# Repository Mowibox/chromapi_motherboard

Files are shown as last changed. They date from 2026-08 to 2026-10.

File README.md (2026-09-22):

# chromapi_motherboard

This repo contains a dedicated control HAT designed to manage the high-speed motion, power distribution, and sensor integration required for the quadruped robot [Chromapi](https://github.com/Mowibox/chromapi).








<p align="center">
  chromapi_motherboard
</p>

*Designed with KiCAD 10.*

## Table of contents

| Section | Description |
| --- | --- |
| [Project overview](#project-overview) | General description of the quadruped control board |
| [Authors](#authors) | Main contributors information |
| [Sponsors & Acknowledgements](#sponsors--acknowledgements) | Information about project sponsors and hardware support |
| [Resources & Documentation](#resources--documentation) | Links to datasheets, BOM, and design architectures |
| [Contributions](#contributions) | How to contribute to the repository |
| [License](#license) | Licensing information |

## Project overview

| Resource | Description | Location | Status |
| :--- | :--- | :--- | :--- |
| **💻 Firmware** | STM32 low-level drivers and communication protocol. | [`/firmware`](./firmware) | **Available** |
| **📐 Schematics** | PDF for hardware architecture | [`/hardware/schematic_pdf`](./hardware/schematic_pdf/chromapi_motherboard_v1.pdf) | **Available** |
| **📦 Manufacturing** | Gerbers, Drill files, BOM, and CPL for assembly. | [`/hardware/production`](./hardware/production/) | **Available** |

### Chromapi's Anatomy

* **🧠 The Brain**: The STM32G431KBT6 MCU handles real-time tasks: servo control, IMU fusion, and power monitoring. The Raspberry Pi runs high-level control, vision, and the Python SDK. They communicate through a custom UART bridge at 1 Mbps.

* **💪 The Muscles**: The SN74LVC1G126 and SN74LVC1G125 buffer the half-duplex RS485 bus for 12 Feetech STS3215 servos. The STM32 polls servo positions at 200 Hz.

* **❤️ The Heart**: The TPS51388 converts the 18650 2S battery voltage to 5V. The LD39050 generates the 3.3V rail. The INA226 monitors voltage, current, and power via I2C.

* **🛡️ The Immune System**: The CN3302 charges the two 18650 Li-ion cells through USB-C. The HY2120 provides protection against over-discharge, over-current, and short circuits.

* **👁️ The Senses & Balance**: The BMI088 IMU gives acceleration and angular velocity data with SPI. A Mahony filter runs at 100 Hz and outputs orientation as a quaternion. Four foot switches detect ground contact for gait timing.

* **🗣️ The Voice & Expression**: The MAX98357A drives the speaker via I2S communication. The ICS-43434 microphone captures audio through I2S. And the SN74AHCT1G125 level-shifts the 3.3V signal to 5V for the WS2812B RGB LEDs.

## Authors

| |
| :---: |
|  |
| [**Ousmane THIONGANE**](https://mowibox.github.io) |

## Sponsors & Acknowledgements

The hardware development of this board relies on the resources provided by the sponsors below.

### PCBWay

**[PCBWay](https://www.pcbway.com)** is a global manufacturer specializing in rapid prototyping and low-volume hardware production, offering advanced PCB fabrication, turnkey assembly, CNC machining, and 3D printing.

<p align="center">
  <a href="https://www.pcbway.com">
    PCBWay
  </a>
</p>

For this project, I utilized their sponsored [PCB manufacturing](https://www.pcbway.com/orderonline.aspx) and [assembly](https://www.pcbway.fr/pcb-assembly.html) (PCBA) services. Beyond fast production, their engineering team excels at detailed file reviews by cross-checking design options, BOMs, and footprints to prevent errors early. Their reliable component sourcing and rigorous verification were of great help in building a high-quality prototype for the Chromapi's motherbard.

---

> Huge thanks to all the hardware folks who reviewed my schematics, or gave me layout tips. I really appreciate your time and support!

## Resources & Documentation

| **⚡ Electrical Specs** | **📄 Bill of Materials** | **📡 Protocol Reference** | **🧠 Software Architecture** |
| :---: | :---: | :---: | :---: |
| Operating voltages, current limits, and thermal ratings. | Detailed BOM with part numbers and unit costs. | Custom UART protocol between RPi and STM32. | Firmware logic, DMA streams, and interrupt priorities. |
| 👉 [**View Specs**]() | 👉 [**View BOM**]() | 👉 [**View Protocol**]() | 👉 [**View Architecture**]() |

### Power Architecture

```mermaid
%%{init: {'themeVariables': {'edgeLabelBackground':'transparent'}}}%%
flowchart TD
    CHG[["USB-C charge<br/>CN3302"]] -.->|"charge → B+ ≈ 7.2–8.4V"| CELLS[("Battery<br/>18650 x2")]
    CELLS -->|"B+/BM/B-"| HY["HY2120<br/>BMS protection"]
    HY -->|"B+"| SW[["Power switch"]]

    SW -->|"V_BATT ≈ 7.2–8.4V"| SHUNT[["INA226 shunt sense<br/>2mΩ"]]
    SHUNT -->|"V_SYS ≈ 7.2–8.4V"| REG5{{"Voltage regulation<br/>TPS51388 · Fsw=600kHz"}}
    SHUNT -->|"V_SYS"| SERVOS(["Servomotors x12<br/>Feetech STS3215-C001"])

    REG5 -->|"+5V"| RPI["Raspberry Pi"]
    REG5 -->|"+5V"| FANPWR(["Fan<br/>Noctua NF-A4x10"])
    REG5 -->|"+5V"| LEDPWR(["RGB LEDs<br/>WS2812B"])
    REG5 -->|"+5V"| REG33{{"Voltage regulation<br/>LD39050 LDO"}}

    REG33 -->|"+3.3V"| MCU["MCU<br/>STM32G431KBT6"]
    REG33 -->|"+3.3V"| IMU["IMU<br/>BMI088"]
    REG33 -->|"+3.3V"| INA["Power monitor<br/>INA226"]
    REG33 -->|"+3.3V"| AUDIO["Speaker + Microphone<br/>MAX98357A / ICS-43434"]

    classDef power fill:#dd2757,color:#ffffff,stroke:none
    classDef voltreg fill:#ea684c,color:#ffffff,stroke:none
    classDef ic fill:#25b3ae,color:#ffffff,stroke:none
    classDef actuator fill:#c027e7,color:#ffffff,stroke:none
    classDef sensor fill:#5c5aed,color:#ffffff,stroke:none

    class CHG,CELLS,HY,SW power
    class REG5,REG33 voltreg
    class MCU,RPI,AUDIO ic
    class SERVOS,FANPWR,LEDPWR actuator
    class SHUNT,IMU,INA sensor
```

### Communication Architecture

```mermaid
%%{init: {'themeVariables': {'edgeLabelBackground':'transparent'}}}%%
flowchart LR
    RPI["Raspberry Pi"]
    MCU["STM32G431KBT6<br/>SYSCLK · 160 MHz"]
    SERVOS(["Servomotors x12<br/>STS3215-C001"])
    IMU["IMU<br/>BMI088"]
    PWR["Power Monitor<br/>INA226"]
    LED(["RGB LEDs<br/>WS2812B"])
    CAM["Wide Angle Camera<br/>IMX219-D160"]
    AUDIO["Speaker + Microphone<br/>MAX98357A / ICS-43434"]
    FAN(["Fan<br/>Noctua NF-A4x10"])

    RPI <-->|"Custom bridge protocol<br/>UART1 · 1 Mbps · 100 Hz control loop"| MCU
    MCU <-->|"RS485 half-duplex<br/>USART2 · 1 Mbps · 200 Hz poll"| SERVOS
    MCU <-->|"SPI1 · 5 MHz · 400 Hz ODR"| IMU
    MCU <-->|"I2C1 · 400 kHz · 10 Hz poll"| PWR
    MCU -->|"PWM+DMA · 800 kHz"| LED

    RPI -->|"CSI-2"| CAM
    RPI <-->|"I2S"| AUDIO
    RPI <-->|"PWM + Tacho"| FAN

    classDef ic fill:#25b3ae,color:#ffffff,stroke:none
    classDef actuator fill:#c027e7,color:#ffffff,stroke:none
    classDef sensor fill:#5c5aed,color:#ffffff,stroke:none

    class RPI,MCU,AUDIO ic
    class SERVOS,LED,FAN actuator
    class IMU,PWR,CAM sensor
```

## Contributions

Contributions are always welcome!

* **Report Issues:** Found an error or have a feature request? Create a new issue [here.](https://github.com/Mowibox/chromapi_motherboard/issues/new/choose)
* **Fix Bugs & Add Features:** Find out where you can lend a hand by checking out [existing issues.](https://github.com/Mowibox/chromapi_motherboard/issues)

## License

This project is licensed under the Apache 2.0 License. See the [LICENSE](https://github.com/Mowibox/chromapi_motherboard/blob/main/LICENSE) file for more details.

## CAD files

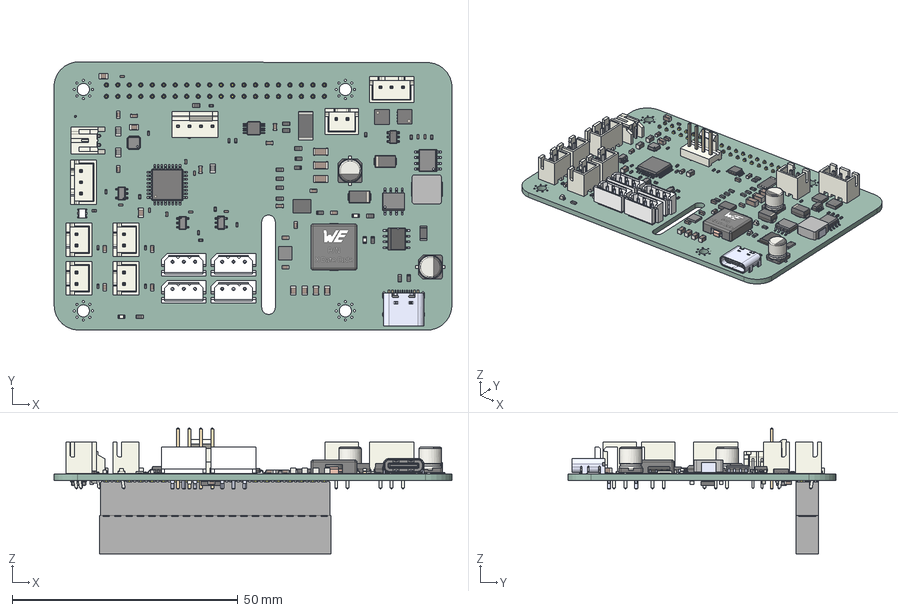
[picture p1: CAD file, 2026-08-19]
hardware/pcb_render/chromapi_motherboard.step
88.1 x 59.4 x 27.8 mm
C_0603_1608Metric x 19
C_0402_1005Metric x 11
R_0402_1005Metric x 17
C_0805_2012Metric x 7
R_0603_1608Metric x 17
JST_S2B_PH_K
JST_B2B_XH_A x 5
CP_Elec_5x58 x 2
TYPE-C-31-M-12
LQFP-32_7x7mm_P0.8mm
D_SMA x 2
JST_B3B_XH_A x 2
5267-03A-X x 4
Fan_Pin_Header_Straight_1x04
LED_0603_1608Metric x 3
DBV5 x 3
R_1206_3216Metric
VSON_8_33x33mm_Pitch065mm_NexFET x 2
C_1206_3216Metric x 3
R_2512_6332Metric
L_0805_2012Metric x 3
VAB0013A_FRAME
VAB0013A_MOLD
21-0102&T1633-4&12
TSSOP-10_3x3mm_P0.5mm
pin5to8_sop8 x 8
sop8_body
AO4406A x 2
WS2812-2020
SOT-23-6
IHLP2525CZER1R0M01
Boden
Deckel
STBC08PMR
Bosch_LGA-16_4.5x3mm_P0.5mm_LayoutBorder7x1y_ClockwisePinNumbering
ESQ-120-33-T-D
InvenSense_ICS-43434-6_3.5x2.65mm
chromapi_motherboard_v1_PCB

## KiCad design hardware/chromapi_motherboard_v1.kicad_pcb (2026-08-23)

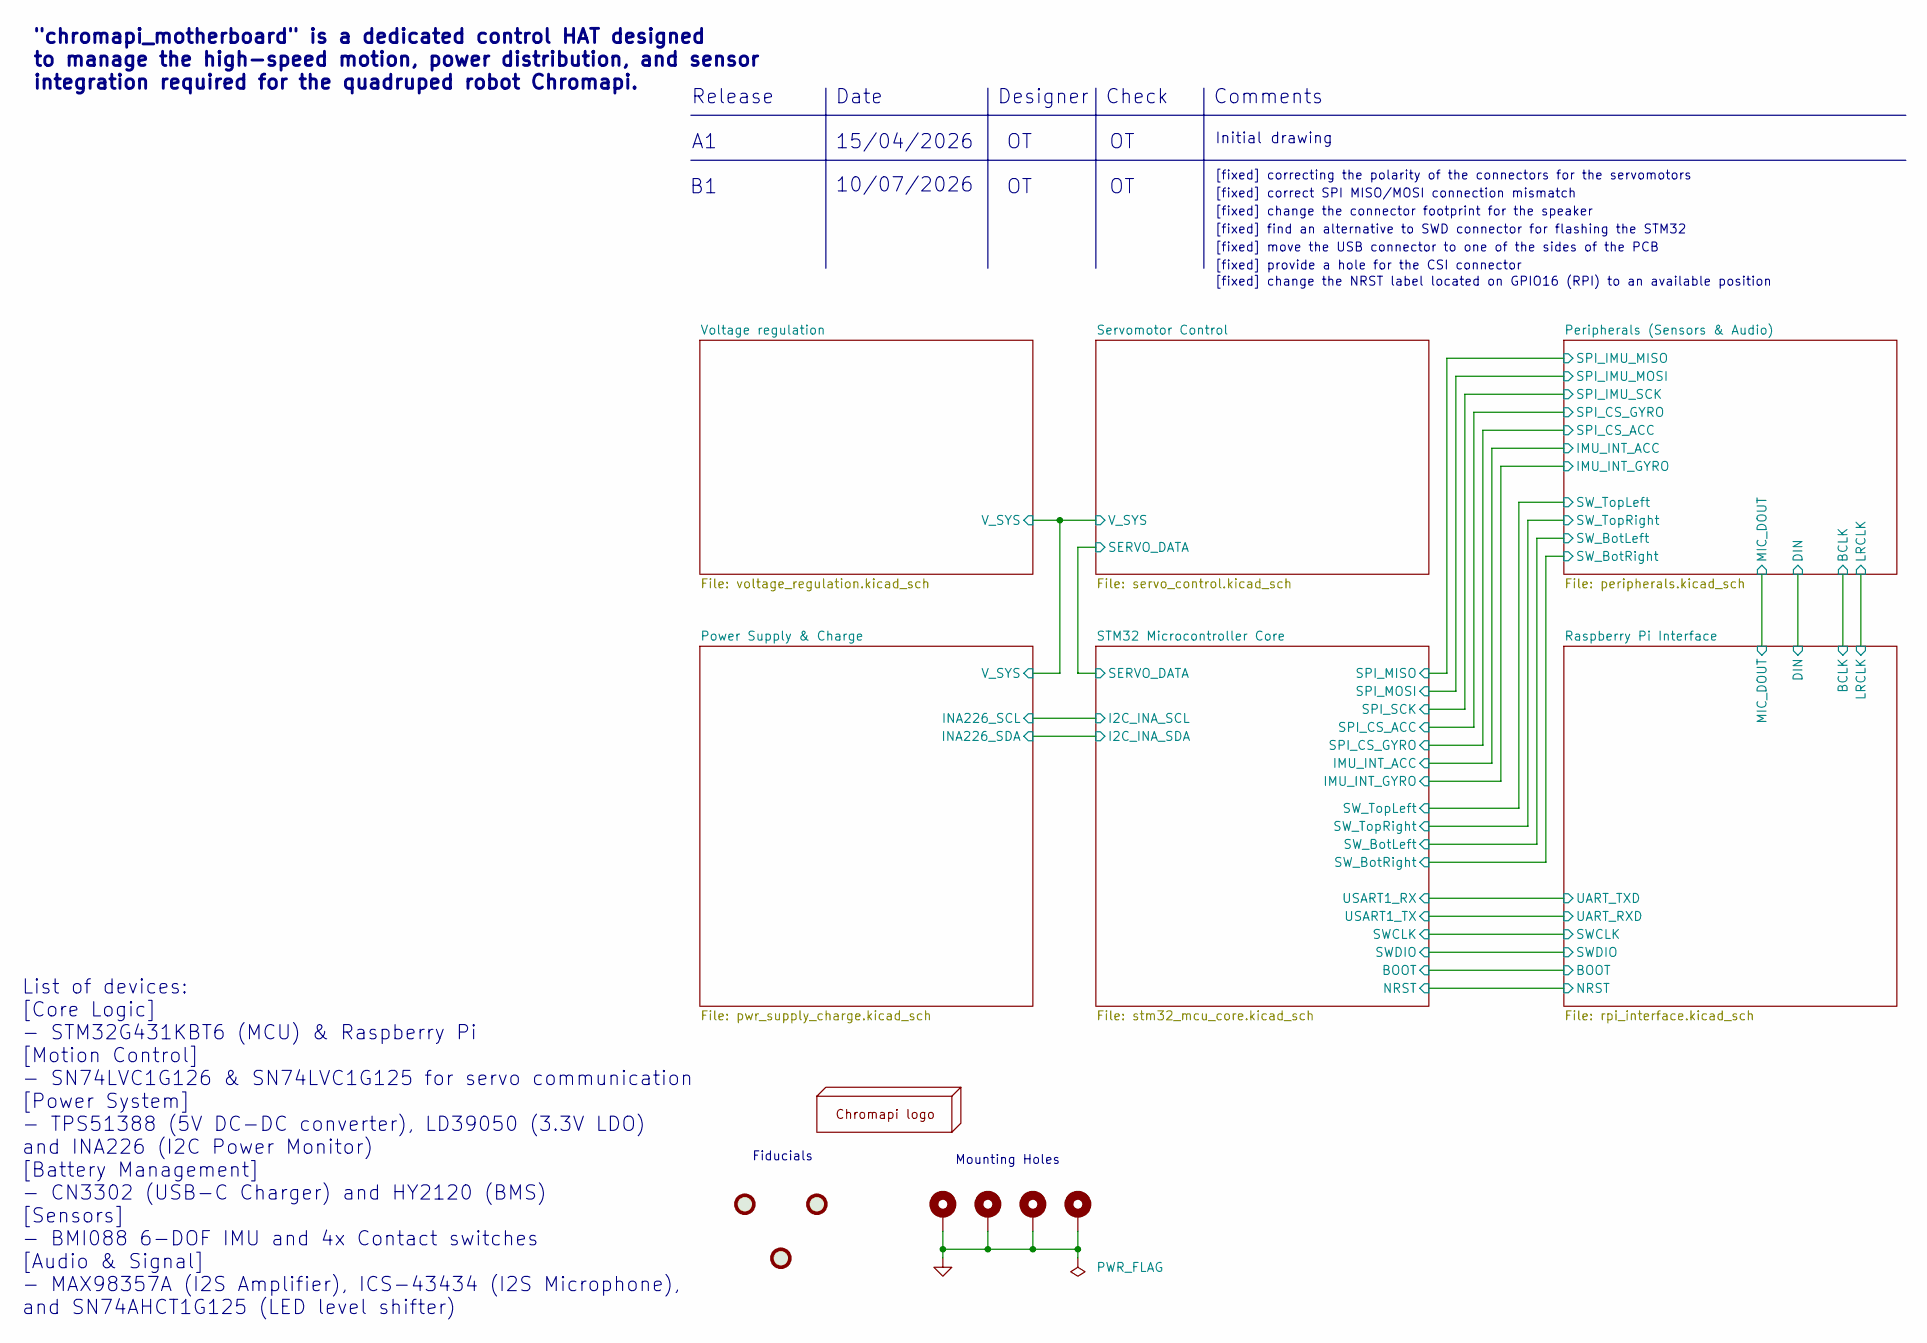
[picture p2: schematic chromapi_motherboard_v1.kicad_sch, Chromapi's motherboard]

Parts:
FID1, FID2, FID3: Fiducial; Fiducial_1mm_Mask2mm
H1: chromapi_logo
H2, H3, H4, H5: MountingHole_Pad; MountingHole_2.7mm_M2.5_Pad_Via

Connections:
GND: H2.1 (1_1), H3.1 (1_1), H4.1 (1_1), H5.1 (1_1); also elsewhere on the board

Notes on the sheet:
[fixed] change the connector footprint for the speaker
[fixed] change the NRST label located on GPIO16 (RPI) to an available position
Check
[fixed] correcting the polarity of the connectors for the servomotors
[fixed] provide a hole for the CSI connector
Initial drawing
Release
10/07/2026
[fixed] move the USB connector to one of the sides of the PCB
[fixed] find an alternative to SWD connector for flashing the STM32
"chromapi_motherboard" is a dedicated control HAT designed to manage the high-speed motion, power distribution, and sensor integration required for the quadruped robot Chromapi.
Date
List of devices: [Core Logic] - STM32G431KBT6 (MCU) & Raspberry Pi [Motion Control] - SN74LVC1G126 & SN74LVC1G125 for servo communication [Power System] - TPS51388 (5V DC-DC converter), LD39050 (3.3V LDO) and INA226 (I2C Power Monitor) [Battery Management] - CN3302 (USB-C Charger) and HY2120 (BMS) 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
Fiducials
15/04/2026
Comments
Designer
Mounting Holes
[fixed] correct SPI MISO/MOSI connection mismatch

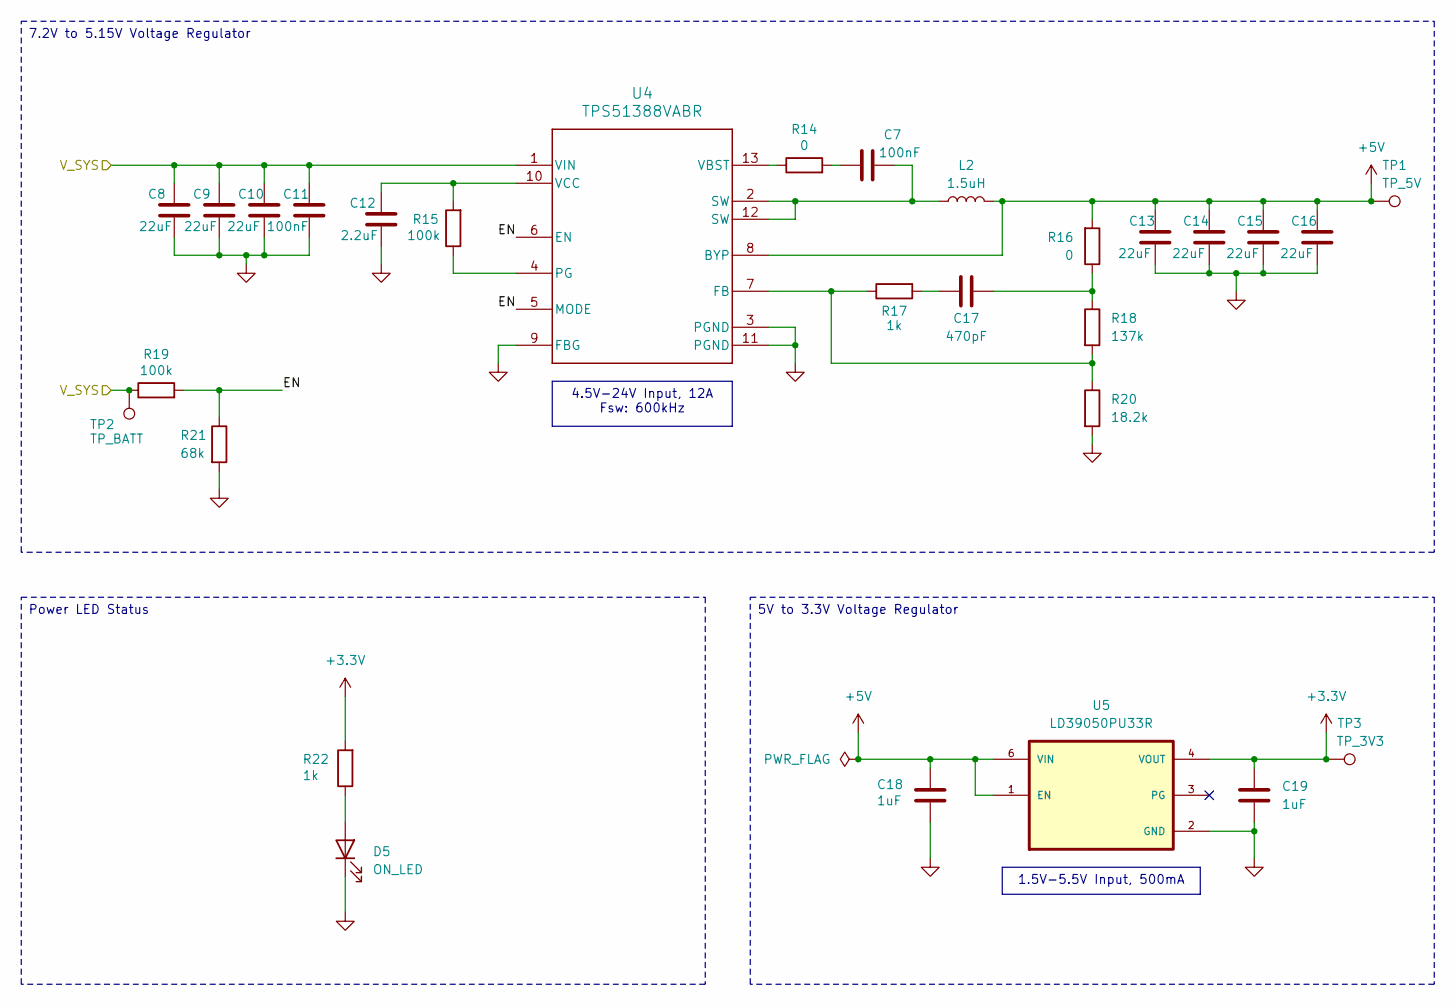
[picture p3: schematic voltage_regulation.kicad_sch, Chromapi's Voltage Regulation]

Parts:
C7: 100nF; C_0603_1608Metric; MPN CL10B104KB8NNNC; JLCPCB Part # C14663
C8, C9, C10: 22uF; C_1206_3216Metric; MPN CL31A226KAHNNNE; JLCPCB Part # C12891
C11: 100nF; C_0603_1608Metric; MPN CC0603KRX7R9BB104; JLCPCB Part # C14663
C12: 2.2uF; C_0603_1608Metric; MPN CL10A225KO8NNNC; JLCPCB Part # C23630
C13, C14, C15, C16: 22uF; C_0805_2012Metric; MPN CL21A226MAQNNNE; JLCPCB Part # C45783
C17: 470pF; C_0603_1608Metric; MPN CC0603JRNPO9BN471; JLCPCB Part # C106211
C18, C19: 1uF; C_0603_1608Metric; MPN CL10A105KB8NNNC; JLCPCB Part # C15849
D5: ON_LED; LED_0603_1608Metric; MPN KT-0603B; JLCPCB Part # C2288
L2: 1.5uH; IND_1040-WE-HCI_WRE; MPN 7443552150; JLCPCB Part # C5914133
R14, R16: 0; R_0603_1608Metric; MPN 0603WAF0000T5E; JLCPCB Part # C21189
R15, R19: 100k; R_0603_1608Metric; MPN CRCW0603100KFKEA; JLCPCB Part # C844916
R17, R22: 1k; R_0603_1608Metric; MPN 0603WAF1001T5E; JLCPCB Part # C21190
R18: 137k; R_0603_1608Metric; MPN 0603WAF1373T5E; JLCPCB Part # C22872
R20: 18.2k; R_0603_1608Metric; MPN RC0603FR-0718K2L; JLCPCB Part # C137784
R21: 68k; R_0603_1608Metric; MPN CRCW060368K0FKEA; JLCPCB Part # C844803
TP1: TP_5V; TestPoint_Pad_D1.5mm
TP2: TP_BATT; TestPoint_Pad_D1.5mm
TP3: TP_3V3; TestPoint_Pad_D1.5mm
U4: TPS51388VABR; TPS513885VABR; MPN TPS513885VABR; JLCPCB Part # C41935536
U5: LD39050PU33R; ld39050PU33R_SON95P300X300X100-7N; MPN LD39050PU33R; DIGI-KEY_PART_NUMBER 497-8716-1-ND

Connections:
+3.3V: C19.1, R22.2, TP3.1 (1_1), U5.4 (VOUT); also elsewhere on the board
+5V: C13.1, C14.1, C15.1, C16.1, C18.1, L2.2, R16.2, TP1.1 (1_1), U4.8 (BYP), U5.1 (EN), U5.6 (VIN); also elsewhere on the board
/Power Supply & Charge/V_SYS: C8.1, C9.1, C10.1, C11.1, R19.1, TP2.1 (1_1), U4.1 (VIN); also elsewhere on the board
/Voltage regulation/EN: R19.2, R21.1, U4.5 (MODE), U4.6 (EN)
GND: C8.2, C9.2, C10.2, C11.2, C12.2, C13.2, C14.2, C15.2, C16.2, C18.2, C19.2, D5.1 (K), R20.2, R21.2, U4.3 (PGND), U4.9 (FBG), U4.11 (PGND), U5.2 (GND), U5.7 (GND); also elsewhere on the board
unnamed: C7.1, L2.1, U4.2 (SW), U4.12 (SW)
unnamed: C7.2, R14.2
unnamed: C17.1, R16.1, R18.1
unnamed: C17.2, R17.2
unnamed: D5.2 (A), R22.1
unnamed: R17.1, R18.2, R20.1, U4.7 (FB)
unnamed: R15.1, U4.4 (PG)
unnamed: R14.1, U4.13 (VBST)
unnamed: C12.1, R15.2, U4.10 (VCC)

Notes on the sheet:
Power LED Status
4.5V-24V Input, 12A Fsw: 600kHz
5V to 3.3V Voltage Regulator
1.5V-5.5V Input, 500mA
7.2V to 5.15V Voltage Regulator

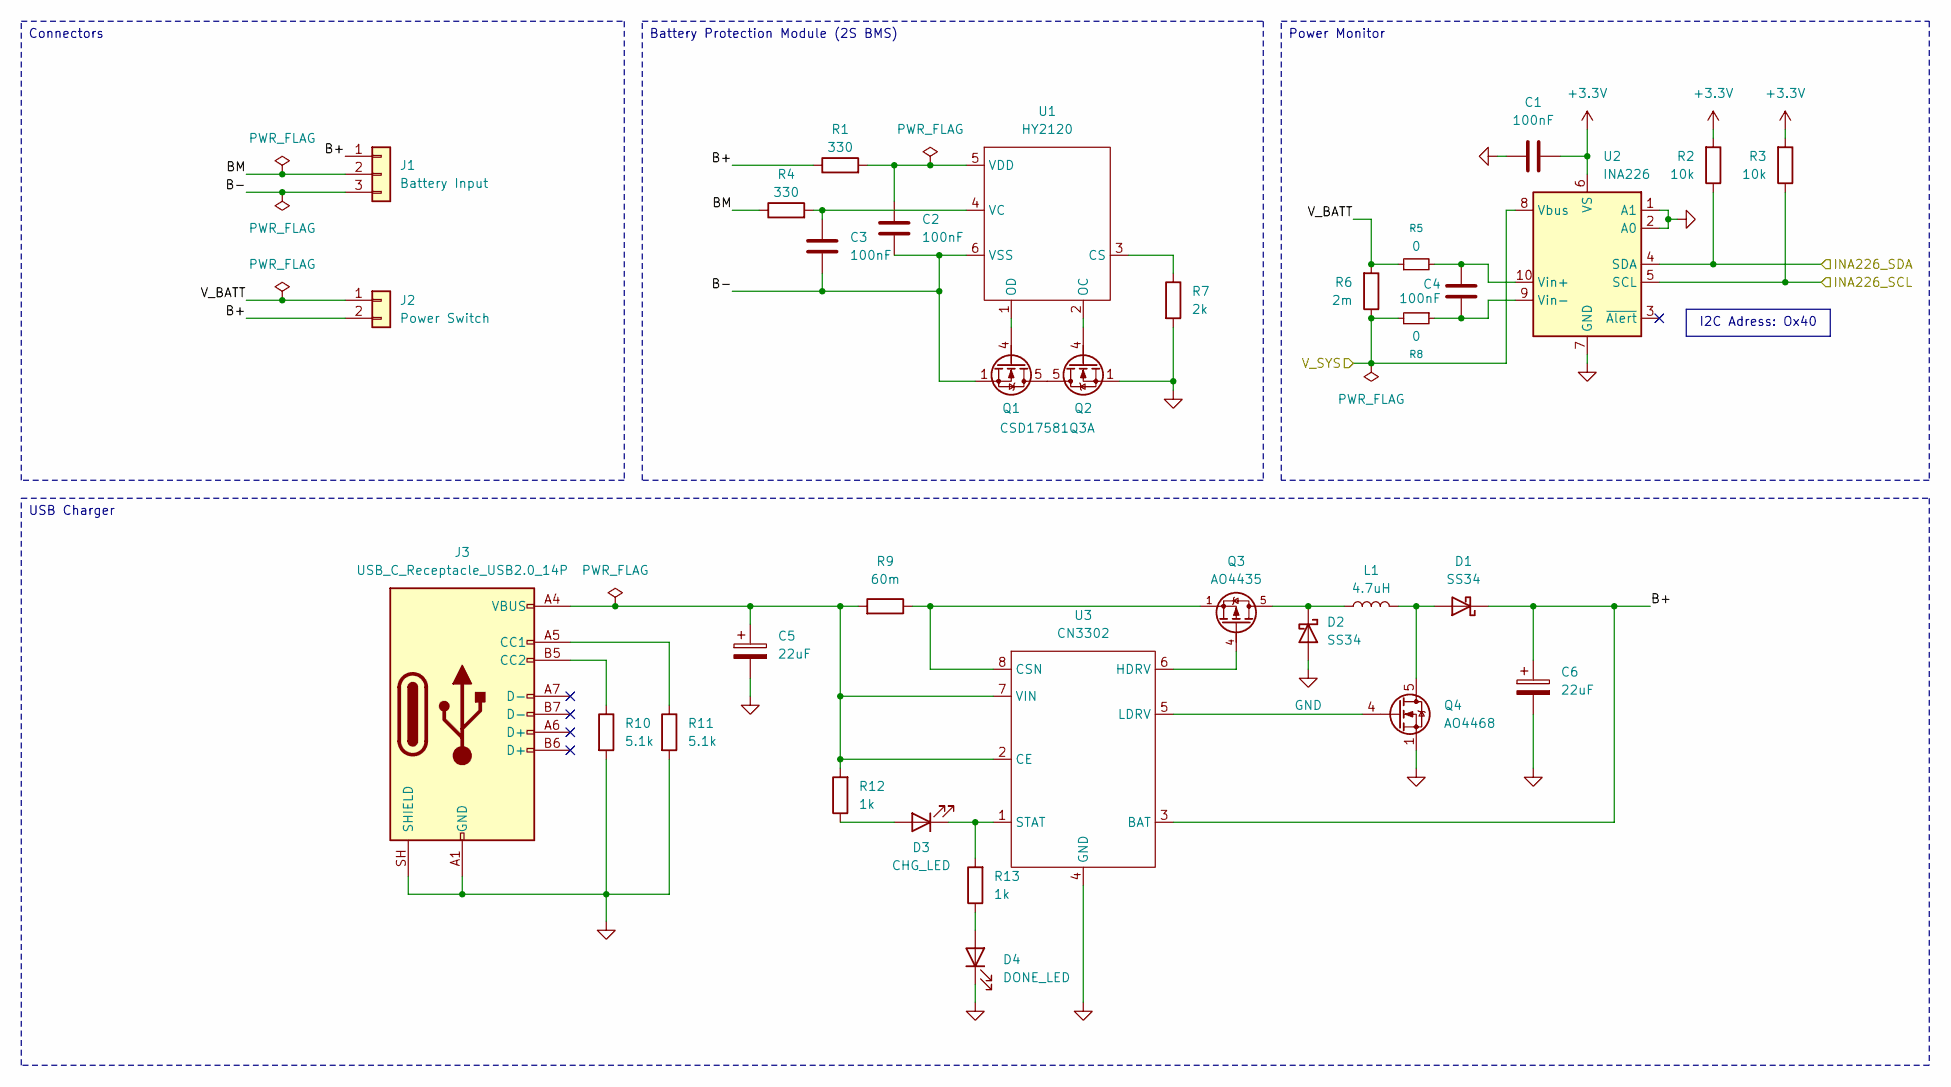
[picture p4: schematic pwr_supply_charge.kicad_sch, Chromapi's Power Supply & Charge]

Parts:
C1, C4: 100nF; C_0603_1608Metric; MPN CC0603KRX7R9BB104; JLCPCB Part # C14663
C2, C3: 100nF; C_0402_1005Metric; MPN CL05B104KB54PNC; JLCPCB Part # C307331
C5, C6: 22uF; CP_Elec_5x5.8; MPN EEEHB1C220R; JLCPCB Part # C336501
D1, D2: SS34; D_SMA; MPN SS34; JLCPCB Part # C8678
D3: CHG_LED; LED_0603_1608Metric; MPN KT-0603R; JLCPCB Part # C2286
D4: DONE_LED; LED_0603_1608Metric; MPN KT-0603G; JLCPCB Part # C12624
J1: Battery Input; JST_XH_B3B-XH-A_1x03_P2.50mm_Vertical
J2: Power Switch; JST_XH_B2B-XH-A_1x02_P2.50mm_Vertical
J3: USB_C_Receptacle_USB2.0_14P; USB_C_Receptacle_HRO_TYPE-C-31-M-12
L1: 4.7uH; INDM6864X300N; MPN IHLP2525CZER4R7M01; JLCPCB Part # C553961
Q1, Q2: CSD17581Q3A; VSON-8_3.3x3.3mm_P0.65mm_NexFET; MPN CSD17581Q3A; JLCPCB Part # C2861705
Q3: AO4435; ao4435_SOIC127P600X175-8N; MPN AO4435; JLCPCB Part # C2944310
Q4: AO4468; ao4435_SOIC127P600X175-8N; MPN AO4468; JLCPCB Part # C87410
R1, R4: 330; R_0402_1005Metric; MPN 0402WGF3300TCE; JLCPCB Part # C25104
R2, R3: 10k; R_0402_1005Metric; MPN 0402WGF1002TCE; JLCPCB Part # C25744
R5, R8: 0; R_0603_1608Metric; MPN 0603WAF0000T5E; JLCPCB Part # C21189
R6: 2m; R_2512_6332Metric; MPN HoYLR2512-2W-2mR-1%; JLCPCB Part # C5375414
R7: 2k; R_0402_1005Metric; MPN 0402WGF2001TCE; JLCPCB Part # C4109
R9: 60m; R_1206_3216Metric; MPN RL1206FR-070R06L; JLCPCB Part # C728501
R10, R11: 5.1k; R_0603_1608Metric; MPN 0603WAF5101T5E; JLCPCB Part # C23186
R12, R13: 1k; R_0603_1608Metric; MPN 0603WAF1001T5E; JLCPCB Part # C21190
U1: HY2120; SOT-23-6; MPN HY2120-CB; JLCPCB Part # C116509
U2: INA226; TSSOP-10_3x3mm_P0.5mm; MPN INA226AQDGSRQ1; JLCPCB Part # C2653835
U3: CN3302; SOP-8_3.76x4.96mm_P1.27mm; MPN CN3302; JLCPCB Part # C559039

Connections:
+3.3V: C1.1, R2.2, R3.2, U2.6 (VS); also elsewhere on the board
/Power Supply & Charge/B+: C6.1, D1.1 (K), J1.1, J2.2, R1.1, U3.3 (BAT)
/Power Supply & Charge/B-: C2.2, C3.2, J1.3, Q1.1 (S), Q1.2 (S), Q1.3 (S), U1.6 (VSS)
/Power Supply & Charge/BM: J1.2, R4.1
/Power Supply & Charge/INA226_SCL: R3.1, U2.5 (SCL); also elsewhere on the board
/Power Supply & Charge/INA226_SDA: R2.1, U2.4 (SDA); also elsewhere on the board
/Power Supply & Charge/V_BATT: J2.1, R5.1, R6.2
/Power Supply & Charge/V_SYS: R6.1, R8.2, U2.8 (Vbus); also elsewhere on the board
GND: C1.2, C5.2, C6.2, D2.2 (A), D4.1 (K), J3.A1 (GND), J3.A12 (GND), J3.B1 (GND), J3.B12 (GND), J3.SH (SHIELD), Q2.1 (S), Q2.2 (S), Q2.3 (S), Q4.1 (S), Q4.2 (S), Q4.3 (S), R7.2, R10.2, R11.2, U2.1 (A1), U2.2 (A0), U2.7 (GND), U3.4 (GND); also elsewhere on the board
unnamed: D1.2 (A), L1.2, Q4.5 (D), Q4.6 (D), Q4.7 (D), Q4.8 (D)
unnamed: D2.1 (K), L1.1, Q3.5, Q3.6, Q3.7, Q3.8
unnamed: D3.2 (A), R12.1
unnamed: D3.1 (K), R13.2, U3.1 (STAT)
unnamed: D4.2 (A), R13.1
unnamed: J3.A5 (CC1), R11.1
unnamed: J3.B5 (CC2), R10.1
unnamed: Q1.5 (D), Q2.5 (D)
unnamed: Q1.4 (G), U1.1 (OD)
unnamed: Q2.4 (G), U1.2 (OC)
unnamed: Q4.4 (G), U3.5 (LDRV)
unnamed: R7.1, U1.3 (CS)
unnamed: C3.1, R4.2, U1.4 (VC)
unnamed: C2.1, R1.2, U1.5 (VDD)
unnamed: C4.1, R5.2, U2.10 (Vin+)
unnamed: C4.2, R8.1, U2.9 (Vin-)
unnamed: C5.1, J3.A4 (VBUS), J3.A9 (VBUS), J3.B4 (VBUS), J3.B9 (VBUS), R9.2, R12.2, U3.2 (CE), U3.7 (VIN)
unnamed: Q3.1, Q3.2, Q3.3, R9.1, U3.8 (CSN)
unnamed: Q3.4, U3.6 (HDRV)

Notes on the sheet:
USB Charger
Connectors
I2C Adress: Ox40
Battery Protection Module (2S BMS)
Power Monitor

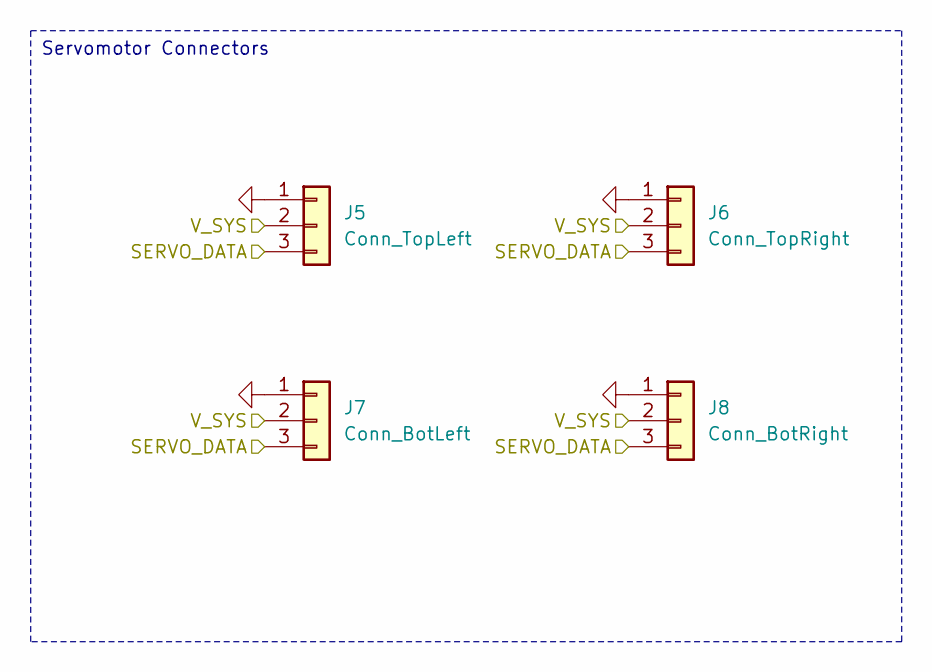
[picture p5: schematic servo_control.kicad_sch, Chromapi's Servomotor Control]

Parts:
J5: Conn_TopLeft; Molex_SPOX_5267-03A_1x03_P2.50mm_Vertical
J6: Conn_TopRight; Molex_SPOX_5267-03A_1x03_P2.50mm_Vertical
J7: Conn_BotLeft; Molex_SPOX_5267-03A_1x03_P2.50mm_Vertical
J8: Conn_BotRight; Molex_SPOX_5267-03A_1x03_P2.50mm_Vertical

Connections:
/Power Supply & Charge/V_SYS: J5.2, J6.2, J7.2, J8.2; also elsewhere on the board
/STM32 Microcontroller Core/SERVO_DATA: J5.3, J6.3, J7.3, J8.3; also elsewhere on the board
GND: J5.1, J6.1, J7.1, J8.1; also elsewhere on the board

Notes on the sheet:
Servomotor Connectors

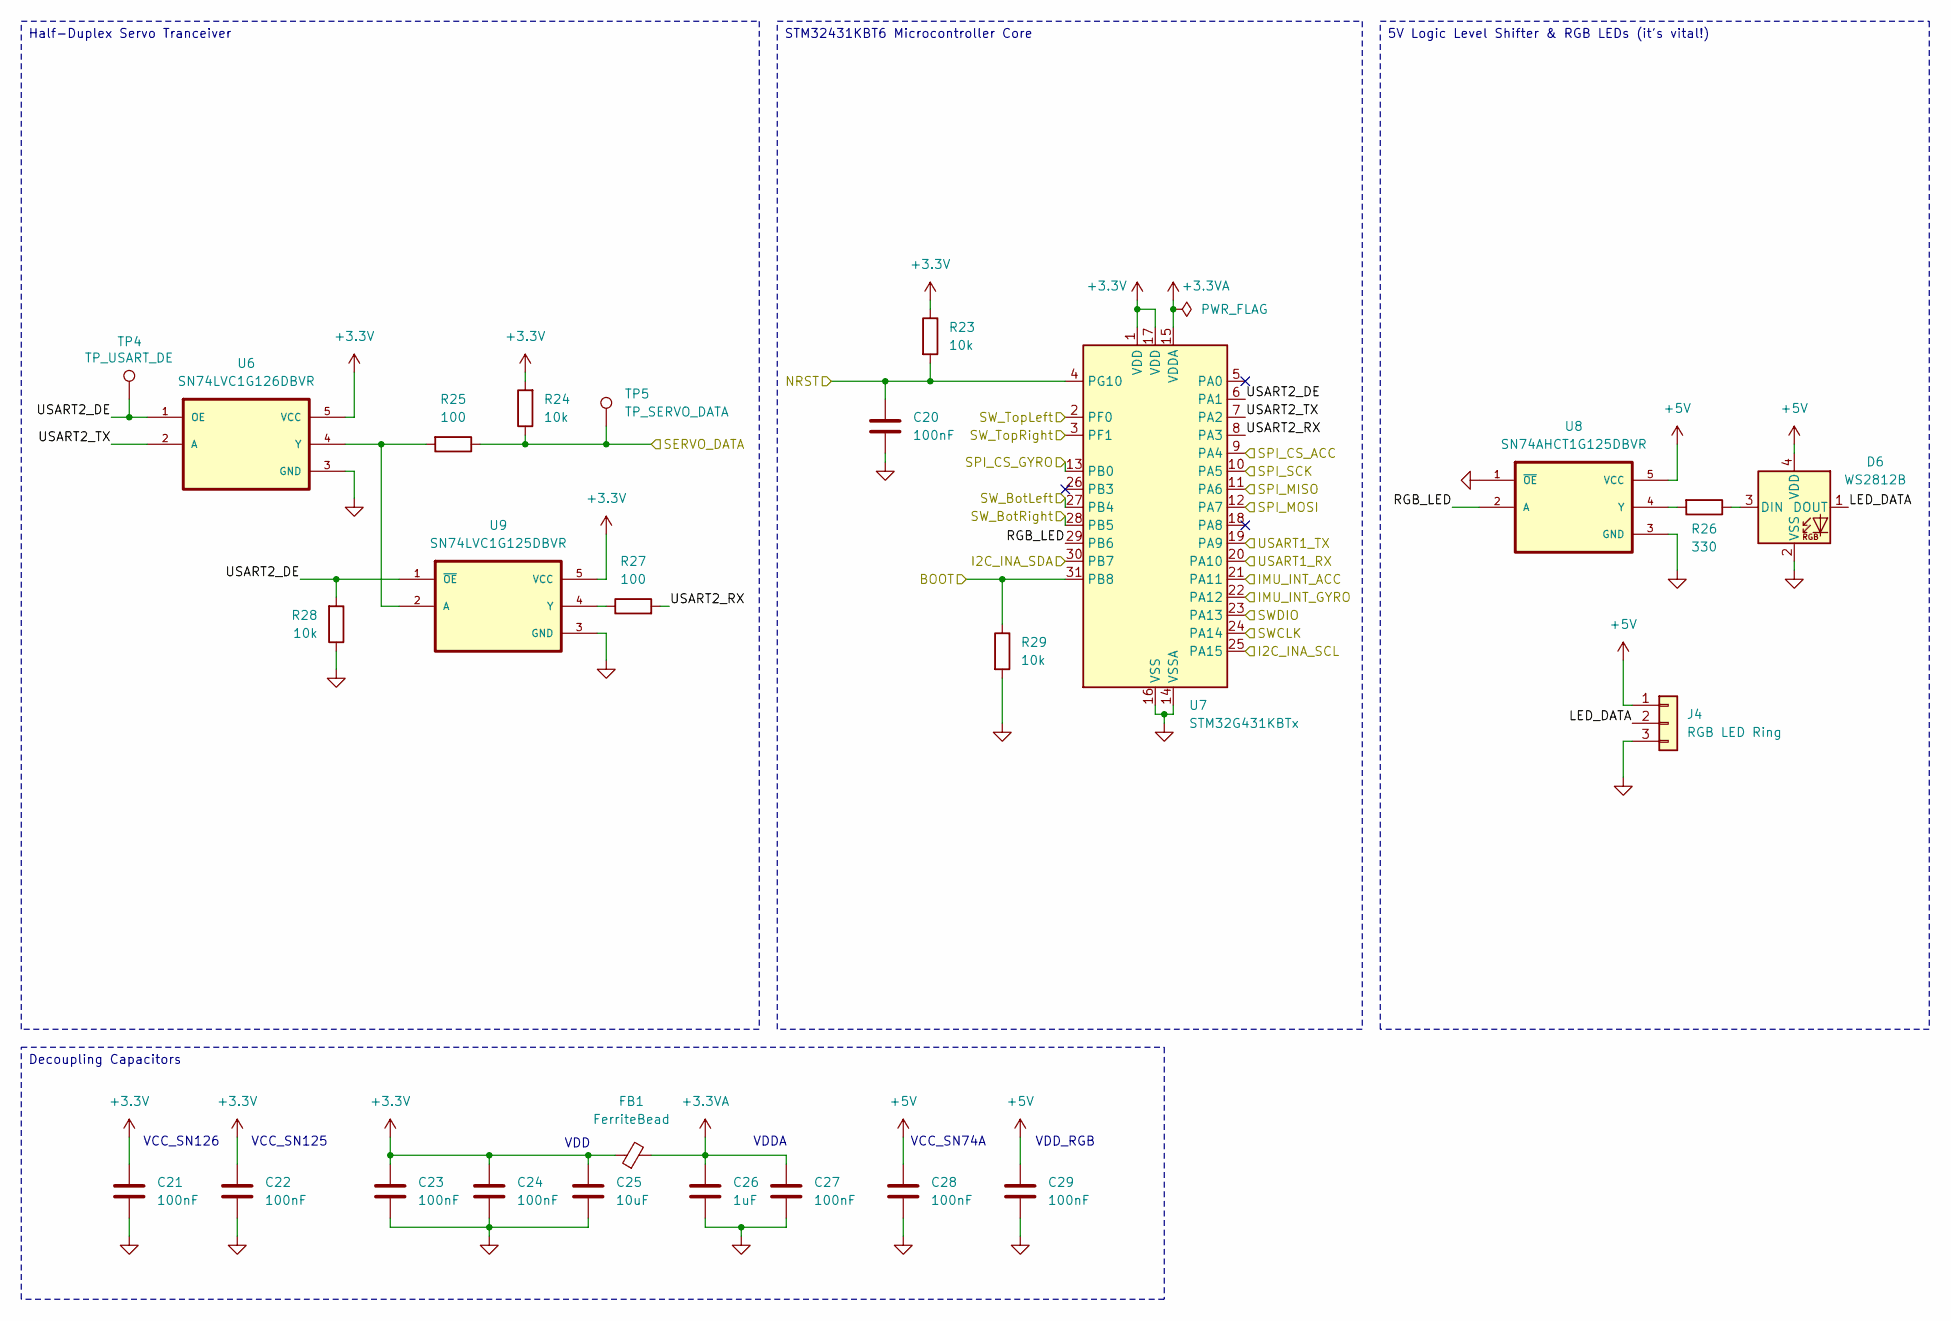
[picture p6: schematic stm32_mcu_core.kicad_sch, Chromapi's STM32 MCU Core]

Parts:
C20, C21, C22, C23, C24, C27, C28, C29: 100nF; C_0402_1005Metric; MPN CL05B104KB54PNC; JLCPCB Part # C307331
C25: 10uF; C_0805_2012Metric; MPN CL21A106KAYNNNE; JLCPCB Part # C15850
C26: 1uF; C_0603_1608Metric; MPN CL10A105KB8NNNC; JLCPCB Part # C15849
D6: WS2812B; LED_WS2812B-2020_PLCC4_2.0x2.0mm; MPN WS2812B-2020; JLCPCB Part # C965555
FB1: FerriteBead; L_0805_2012Metric; MPN MPZ2012S331AT000; JLCPCB Part # C76819
J4: RGB LED Ring; JST_XH_B3B-XH-A_1x03_P2.50mm_Vertical
R23, R24, R28, R29: 10k; R_0402_1005Metric; MPN 0402WGF1002TCE; JLCPCB Part # C25744
R25, R27: 100; R_0402_1005Metric; MPN 0402WGF1000TCE; JLCPCB Part # C25076
R26: 330; R_0402_1005Metric; MPN 0402WGF3300TCE; JLCPCB Part # C25104
TP4: TP_USART_DE; TestPoint_Pad_D1.0mm
TP5: TP_SERVO_DATA; TestPoint_Pad_D1.0mm
U6: SN74LVC1G126DBVR; SOT95P280X145-5N; MPN SN74LVC1G126DBVR; JLCPCB Part # C7834
U7: STM32G431KBTx; LQFP-32_7x7mm_P0.8mm; MPN STM32G431KBT6; JLCPCB Part # C529357
U8: SN74AHCT1G125DBVR; SOT95P280X145-5N; MPN SN74AHCT1G125DBVR; JLCPCB Part # C7484
U9: SN74LVC1G125DBVR; SOT95P280X145-5N; MPN SN74LVC1G125DBVR; JLCPCB Part # C23654

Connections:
+3.3V: C21.1, C22.1, C23.1, C24.1, C25.1, FB1.1, R23.1, R24.2, U6.5 (VCC), U7.1 (VDD), U7.17 (VDD), U9.5 (VCC); also elsewhere on the board
+3.3VA: C26.1, C27.1, FB1.2, U7.15 (VDDA)
+5V: C28.1, C29.1, D6.4 (VDD), J4.1, U8.5 (VCC); also elsewhere on the board
/Peripherals (Sensors & Audio)/IMU_INT_ACC: U7.21 (PA11); also elsewhere on the board
/Peripherals (Sensors & Audio)/IMU_INT_GYRO: U7.22 (PA12); also elsewhere on the board
/Peripherals (Sensors & Audio)/SPI_CS_ACC: U7.13 (PB0); also elsewhere on the board
/Peripherals (Sensors & Audio)/SPI_CS_GYRO: U7.9 (PA4); also elsewhere on the board
/Peripherals (Sensors & Audio)/SPI_IMU_MISO: U7.11 (PA6); also elsewhere on the board
/Peripherals (Sensors & Audio)/SPI_IMU_MOSI: U7.12 (PA7); also elsewhere on the board
/Peripherals (Sensors & Audio)/SPI_IMU_SCK: U7.10 (PA5); also elsewhere on the board
/Peripherals (Sensors & Audio)/SW_BotLeft: U7.27 (PB4); also elsewhere on the board
/Peripherals (Sensors & Audio)/SW_BotRight: U7.28 (PB5); also elsewhere on the board
/Peripherals (Sensors & Audio)/SW_TopLeft: U7.2 (PF0); also elsewhere on the board
/Peripherals (Sensors & Audio)/SW_TopRight: U7.3 (PF1); also elsewhere on the board
/Power Supply & Charge/INA226_SCL: U7.25 (PA15); also elsewhere on the board
/Power Supply & Charge/INA226_SDA: U7.30 (PB7); also elsewhere on the board
/Raspberry Pi Interface/BOOT: R29.1, U7.31 (PB8); also elsewhere on the board
/Raspberry Pi Interface/NRST: C20.1, R23.2, U7.4 (PG10); also elsewhere on the board
/Raspberry Pi Interface/SWCLK: U7.24 (PA14); also elsewhere on the board
/Raspberry Pi Interface/SWDIO: U7.23 (PA13); also elsewhere on the board
/Raspberry Pi Interface/UART_RXD: U7.19 (PA9); also elsewhere on the board
/Raspberry Pi Interface/UART_TXD: U7.20 (PA10); also elsewhere on the board
/STM32 Microcontroller Core/LED_DATA: D6.1 (DOUT), J4.2
/STM32 Microcontroller Core/RGB_LED: U7.29 (PB6), U8.2 (A)
/STM32 Microcontroller Core/SERVO_DATA: R24.1, R25.1, TP5.1 (1_1); also elsewhere on the board
/STM32 Microcontroller Core/USART2_DE: R28.2, TP4.1 (1_1), U6.1 (OE), U7.6 (PA1), U9.1 (~OE)
/STM32 Microcontroller Core/USART2_RX: R27.2, U7.8 (PA3)
/STM32 Microcontroller Core/USART2_TX: U6.2 (A), U7.7 (PA2)
GND: C20.2, C21.2, C22.2, C23.2, C24.2, C25.2, C26.2, C27.2, C28.2, C29.2, D6.2 (VSS), J4.3, R28.1, R29.2, U6.3 (GND), U7.14 (VSSA), U7.16 (VSS), U7.32 (VSS), U8.1 (~OE), U8.3 (GND), U9.3 (GND); also elsewhere on the board
unnamed: D6.3 (DIN), R26.1
unnamed: R25.2, U6.4 (Y), U9.2 (A)
unnamed: R26.2, U8.4 (Y)
unnamed: R27.1, U9.4 (Y)

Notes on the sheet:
VCC_SN74A
VDD
VCC_SN126
VDD_RGB
VCC_SN125
VDDA
STM32431KBT6 Microcontroller Core
5V Logic Level Shifter & RGB LEDs (it's vital!)
Half-Duplex Servo Tranceiver
Decoupling Capacitors

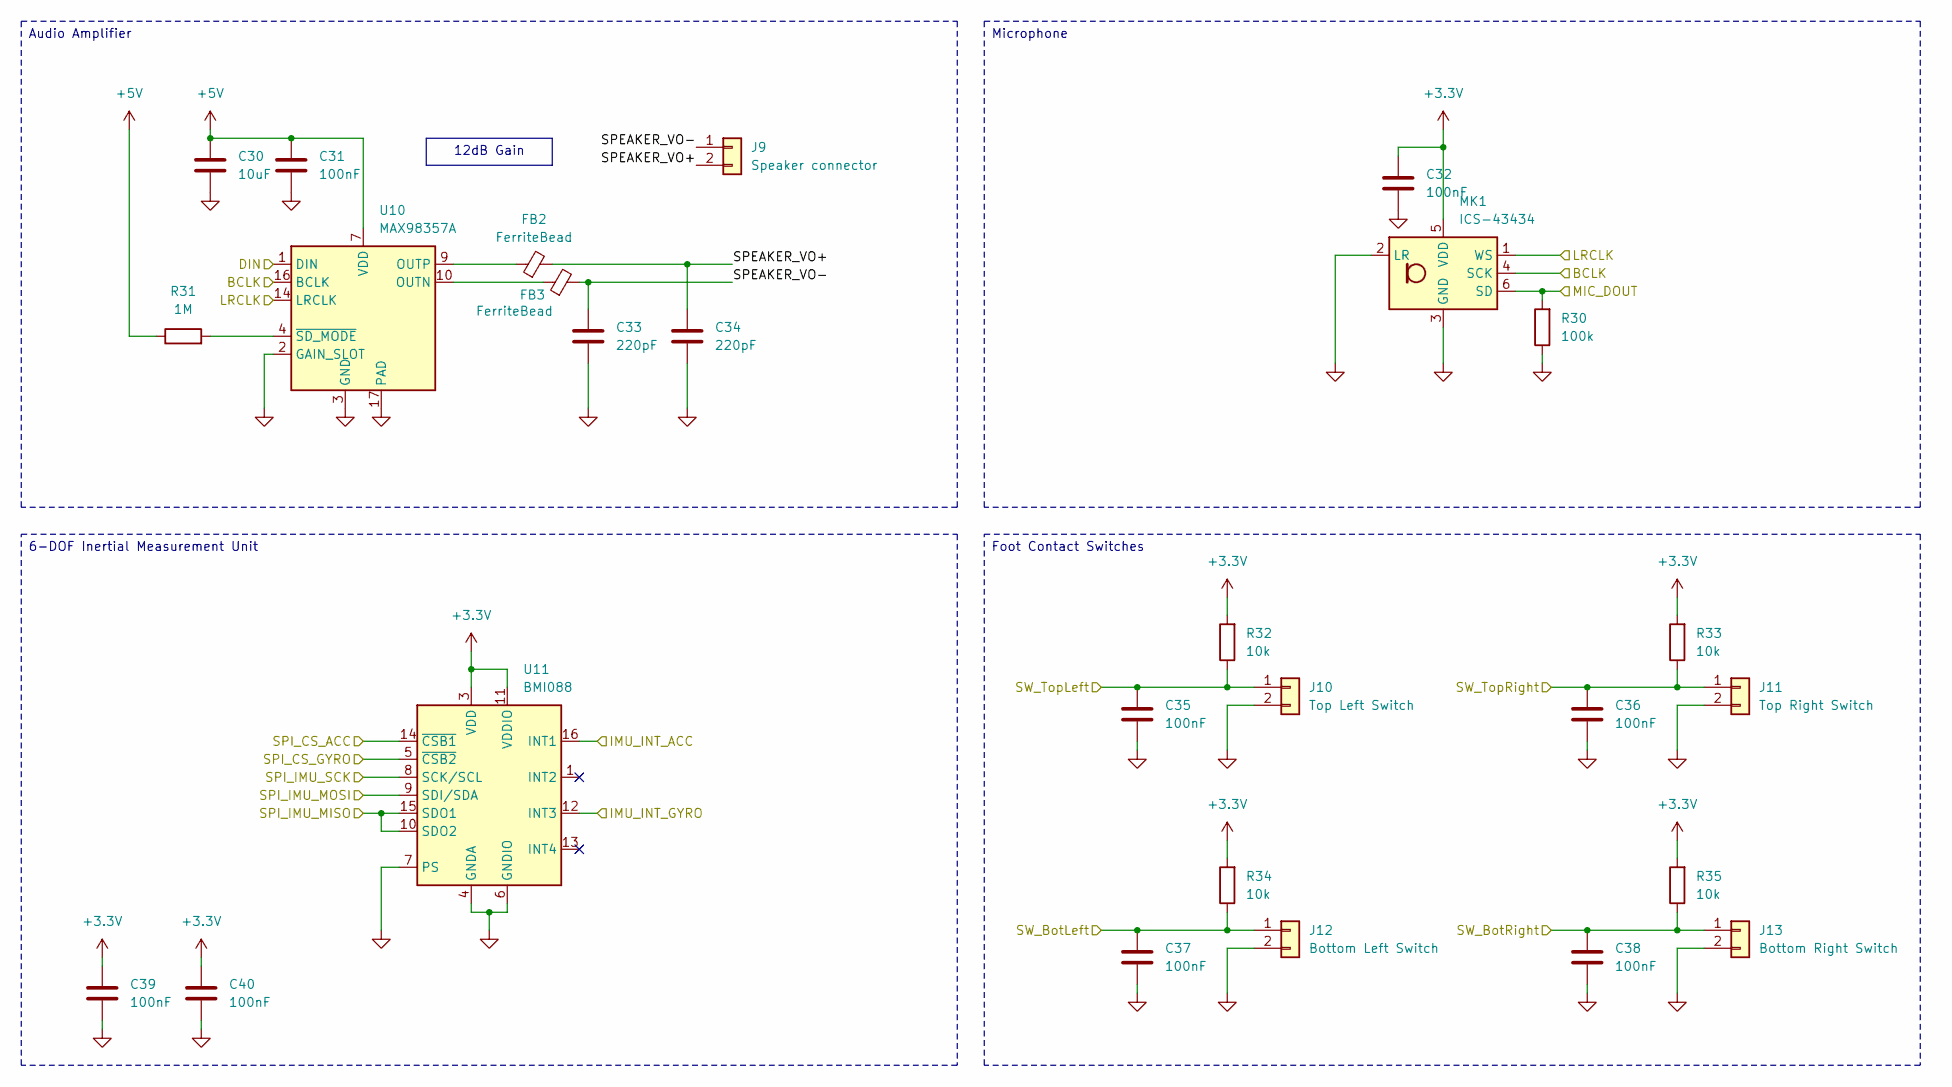
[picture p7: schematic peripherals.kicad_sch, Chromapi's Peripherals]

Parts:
C30: 10uF; C_0805_2012Metric; MPN CL21A106KAYNNNE; JLCPCB Part # C15850
C31, C32, C35, C36, C37, C38, C39, C40: 100nF; C_0603_1608Metric; MPN CC0603KRX7R9BB104; JLCPCB Part # C14663
C33, C34: 220pF; C_0603_1608Metric; MPN CL10B221KB8NNNC; JLCPCB Part # C1603
FB2, FB3: FerriteBead; L_0805_2012Metric; MPN MPZ2012S331AT000; JLCPCB Part # C76819
J9: Speaker connector; JST_PH_S2B-PH-K_1x02_P2.00mm_Horizontal
J10: Top Left Switch; JST_XH_B2B-XH-A_1x02_P2.50mm_Vertical
J11: Top Right Switch; JST_XH_B2B-XH-A_1x02_P2.50mm_Vertical
J12: Bottom Left Switch; JST_XH_B2B-XH-A_1x02_P2.50mm_Vertical
J13: Bottom Right Switch; JST_XH_B2B-XH-A_1x02_P2.50mm_Vertical
MK1: ICS-43434; InvenSense_ICS-43434-6_3.5x2.65mm; MPN ICS-43434; JLCPCB Part # C5656610
R30: 100k; R_0603_1608Metric; MPN 0603WAF1003T5E; JLCPCB Part # C25803
R31: 1M; R_0402_1005Metric; MPN 0402WGF1004TCE; JLCPCB Part # C26083
R32, R33, R34, R35: 10k; R_0402_1005Metric; MPN 0402WGF1002TCE; JLCPCB Part # C25744
U10: MAX98357A; TQFN-16-1EP_3x3mm_P0.5mm_EP1.23x1.23mm; MPN MAX98357AETE+T; JLCPCB Part # C910544
U11: BMI088; Bosch_LGA-16_4.5x3mm_P0.5mm_LayoutBorder7x1y_ClockwisePinNu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; MPN BMI088; JLCPCB Part # C194919

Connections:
+3.3V: C32.1, C39.1, C40.1, MK1.5 (VDD), R32.2, R33.2, R34.2, R35.2, U11.3 (VDD), U11.11 (VDDIO); also elsewhere on the board
+5V: C30.1, C31.1, R31.1, U10.7 (VDD), U10.8 (VDD); also elsewhere on the board
/Peripherals (Sensors & Audio)/BCLK: MK1.4 (SCK), U10.16 (BCLK); also elsewhere on the board
/Peripherals (Sensors & Audio)/DIN: U10.1 (DIN); also elsewhere on the board
/Peripherals (Sensors & Audio)/IMU_INT_ACC: U11.16 (INT1); also elsewhere on the board
/Peripherals (Sensors & Audio)/IMU_INT_GYRO: U11.12 (INT3); also elsewhere on the board
/Peripherals (Sensors & Audio)/LRCLK: MK1.1 (WS), U10.14 (LRCLK); also elsewhere on the board
/Peripherals (Sensors & Audio)/MIC_DOUT: MK1.6 (SD), R30.2; also elsewhere on the board
/Peripherals (Sensors & Audio)/SPEAKER_VO+: C34.1, FB2.2, J9.2
/Peripherals (Sensors & Audio)/SPEAKER_VO-: C33.1, FB3.2, J9.1
/Peripherals (Sensors & Audio)/SPI_CS_ACC: U11.14 (~CSB1); also elsewhere on the board
/Peripherals (Sensors & Audio)/SPI_CS_GYRO: U11.5 (~CSB2); also elsewhere on the board
/Peripherals (Sensors & Audio)/SPI_IMU_MISO: U11.10 (SDO2), U11.15 (SDO1); also elsewhere on the board
/Peripherals (Sensors & Audio)/SPI_IMU_MOSI: U11.9 (SDI/SDA); also elsewhere on the board
/Peripherals (Sensors & Audio)/SPI_IMU_SCK: U11.8 (SCK/SCL); also elsewhere on the board
/Peripherals (Sensors & Audio)/SW_BotLeft: C37.1, J12.1, R34.1; also elsewhere on the board
/Peripherals (Sensors & Audio)/SW_BotRight: C38.1, J13.1, R35.1; also elsewhere on the board
/Peripherals (Sensors & Audio)/SW_TopLeft: C35.1, J10.1, R32.1; also elsewhere on the board
/Peripherals (Sensors & Audio)/SW_TopRight: C36.1, J11.1, R33.1; also elsewhere on the board
GND: C30.2, C31.2, C32.2, C33.2, C34.2, C35.2, C36.2, C37.2, C38.2, C39.2, C40.2, J10.2, J11.2, J12.2, J13.2, MK1.2 (LR), MK1.3 (GND), R30.1, U10.2 (GAIN_SLOT), U10.3 (GND), U10.11 (GND), U10.15 (GND), U10.17 (PAD), U11.2 (GNDA), U11.4 (GNDA), U11.6 (GNDIO), U11.7 (PS); also elsewhere on the board
unnamed: FB3.1, U10.10 (OUTN)
unnamed: FB2.1, U10.9 (OUTP)
unnamed: R31.2, U10.4 (~SD_MODE)

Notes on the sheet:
12dB Gain
Audio Amplifier
6-DOF Inertial Measurement Unit
Microphone
Foot Contact Switches

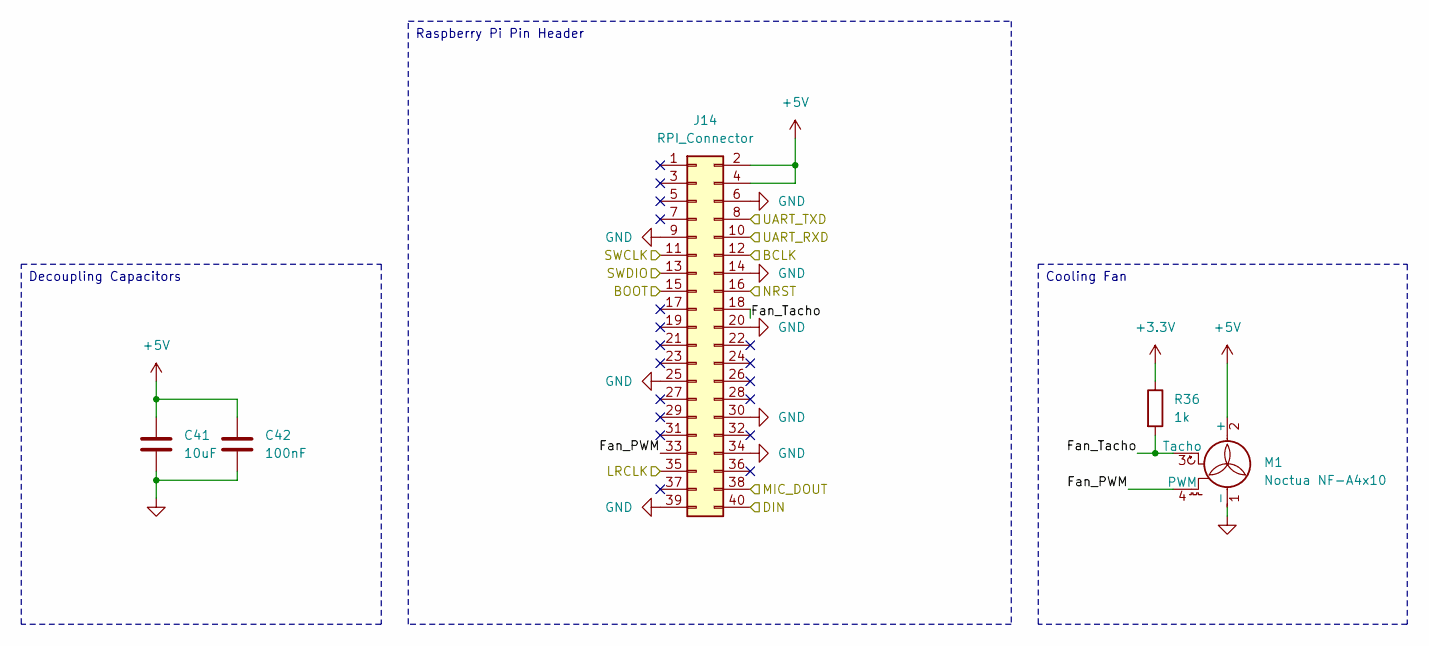
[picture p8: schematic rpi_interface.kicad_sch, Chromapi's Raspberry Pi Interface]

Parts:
C41: 10uF; C_0805_2012Metric; MPN CL21A106KAYNNNE; JLCPCB Part # C15850
C42: 100nF; C_0402_1005Metric; MPN CL05B104KB54PNC; JLCPCB Part # C307331
J14: RPI_Connector; PinSocket_2x20_P2.54mm_Vertical; MPN ESQ-120-13-G-D
M1: Noctua NF-A4x10; FanPinHeader_1x04_P2.54mm_Vertical; MPN 470531000; JLCPCB Part # C240840
R36: 1k; R_0603_1608Metric; MPN 0603WAF1001T5E; JLCPCB Part # C21190

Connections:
+3.3V: R36.1; also elsewhere on the board
+5V: C41.1, C42.1, J14.2, J14.4, M1.2 (+); also elsewhere on the board
/Peripherals (Sensors & Audio)/BCLK: J14.12; also elsewhere on the board
/Peripherals (Sensors & Audio)/DIN: J14.40; also elsewhere on the board
/Peripherals (Sensors & Audio)/LRCLK: J14.35; also elsewhere on the board
/Peripherals (Sensors & Audio)/MIC_DOUT: J14.38; also elsewhere on the board
/Raspberry Pi Interface/BOOT: J14.15; also elsewhere on the board
/Raspberry Pi Interface/Fan_PWM: J14.33, M1.4 (PWM)
/Raspberry Pi Interface/Fan_Tacho: J14.18, M1.3 (Tacho), R36.2
/Raspberry Pi Interface/NRST: J14.16; also elsewhere on the board
/Raspberry Pi Interface/SWCLK: J14.11; also elsewhere on the board
/Raspberry Pi Interface/SWDIO: J14.13; also elsewhere on the board
/Raspberry Pi Interface/UART_RXD: J14.10; also elsewhere on the board
/Raspberry Pi Interface/UART_TXD: J14.8; also elsewhere on the board
GND: C41.2, C42.2, J14.6, J14.9, J14.14, J14.20, J14.25, J14.30, J14.34, J14.39, M1.1 (-); also elsewhere on the board

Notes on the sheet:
Cooling Fan
Decoupling Capacitors
Raspberry Pi Pin Header

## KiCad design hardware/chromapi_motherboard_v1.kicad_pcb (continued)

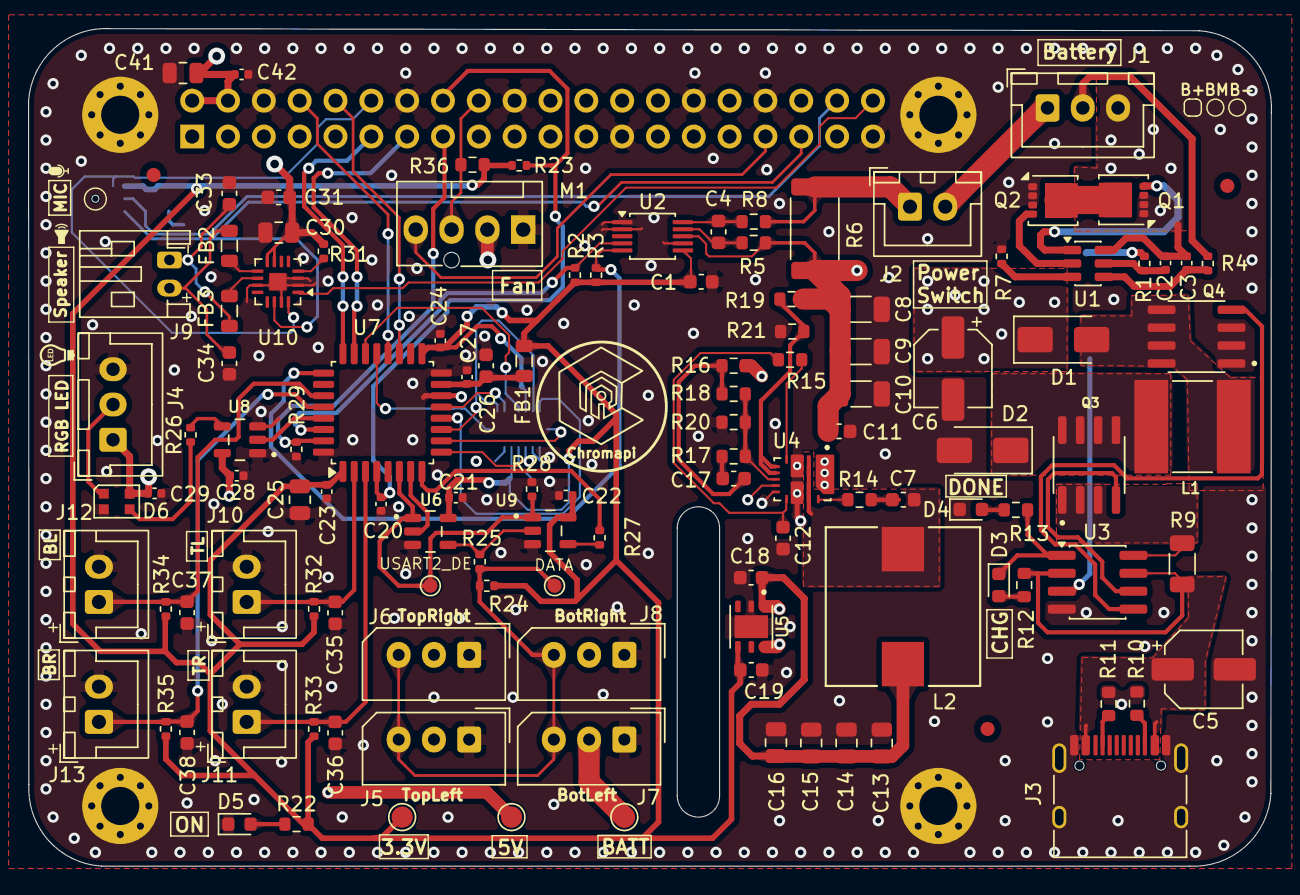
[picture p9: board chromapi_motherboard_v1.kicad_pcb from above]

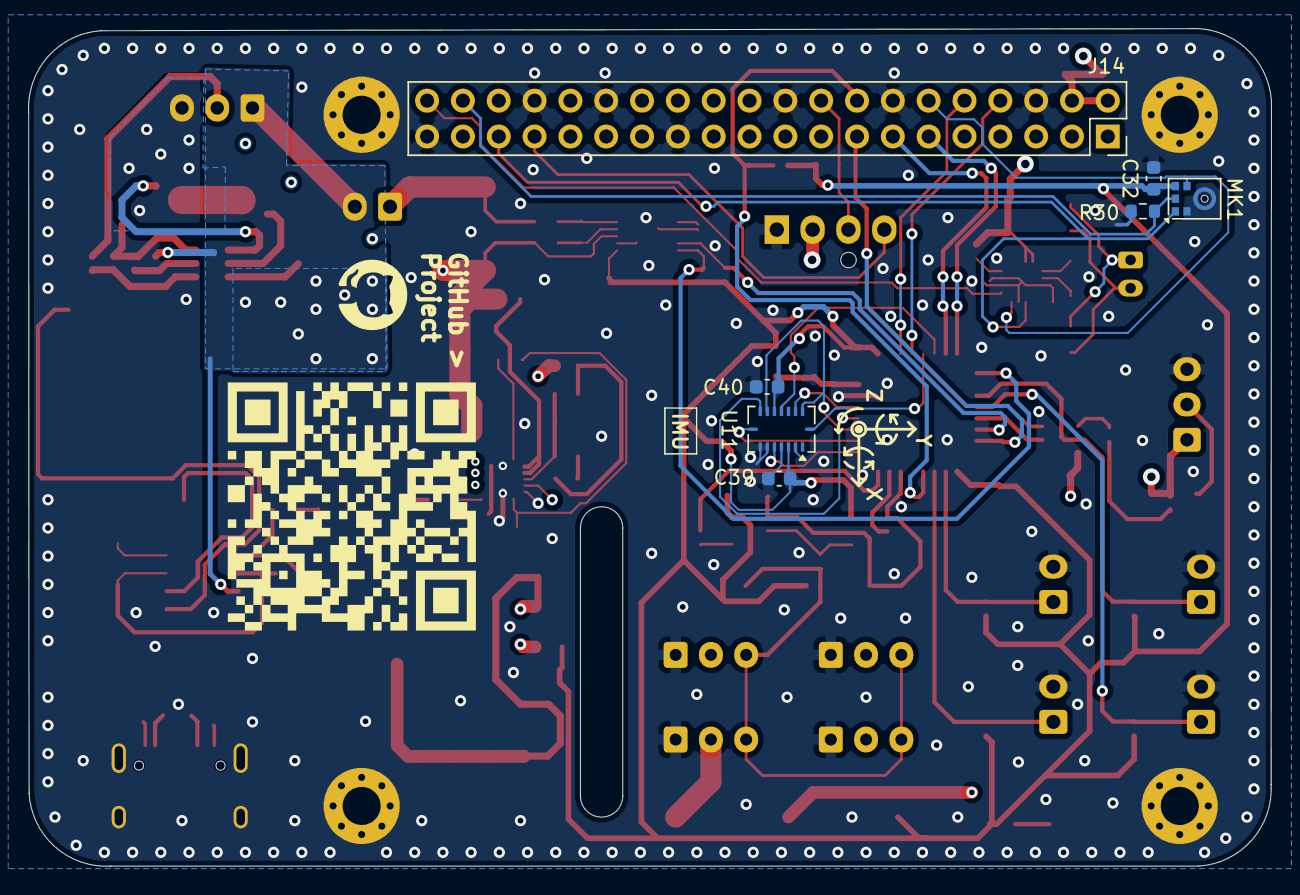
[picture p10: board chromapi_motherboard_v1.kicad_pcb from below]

Board: 4 copper layers, 88.1 x 59.4 mm, 133 parts (7 on the bottom side), 78 nets.

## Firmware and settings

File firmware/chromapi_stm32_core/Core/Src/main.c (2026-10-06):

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
/* Includes ------------------------------------------------------------------*/
#include "main.h"

/* USER CODE BEGIN Includes */
#include <stdio.h>
#include <string.h>
#include <ws2812b.h>

#include "sts3215_hal.h"
#include "sts3215_protocol.h"
#include "ina226.h"
#include "bmi088.h"
#include "bridge.h"
#include "cordic_sqrt.h"
#include "mahony.h"
/* USER CODE END Includes */

/* USER CODE BEGIN PD */
#define INA226_I2C_ADDR    0x40
#define SHUNT_OHMS         0.002
#define MAX_CURRENT_A      8.0
/* USER CODE END PD */

CORDIC_HandleTypeDef hcordic;

I2C_HandleTypeDef hi2c1;

SPI_HandleTypeDef hspi1;

TIM_HandleTypeDef htim4;
TIM_HandleTypeDef htim6;
DMA_HandleTypeDef hdma_tim4_ch1;

UART_HandleTypeDef huart1;
UART_HandleTypeDef huart2;
DMA_HandleTypeDef hdma_usart1_rx;
DMA_HandleTypeDef hdma_usart1_tx;
DMA_HandleTypeDef hdma_usart2_tx;
DMA_HandleTypeDef hdma_usart2_rx;

/* USER CODE BEGIN PV */
AutoFox_INA226 gINA226;
STS3215_HAL_Handle_t hservo;
BMI088 gIMU;
MahonyFilter_t g_mahony;

volatile uint8_t  g_reply_received  = 0;
volatile uint8_t  g_reply_id        = 0;
volatile uint8_t  g_reply_error     = 0;
volatile uint8_t  g_reply_data_len  = 0;
volatile uint8_t  g_reply_data[STS3215_REPLY_DATA_MAX] = {0};
volatile STS3215_Status_t g_reply_status = STS3215_OK;
uint32_t last_led_update = 0;

volatile servo_txn_type_t g_servo_txn = SERVO_TXN_NONE;
static volatile bool g_poll_due = false;
static uint8_t g_poll_count = 0;
#define SERVO_POLL_PERIOD_MS 5U  // 200 Hz

static uint8_t active_servo_ids[12];
static uint8_t active_servo_count = 0;

static volatile bool g_imu_task_due = false;
static volatile bool g_power_task_due = false;

static uint8_t g_tim6_div = 0; // servo poll ODR = 200 Hz (TIM6 base is 400 Hz)
static uint8_t g_tim6_power_div = 0; // INA226 refresh ODR = 10 Hz (400 Hz / 40)
static uint32_t g_imu_last_tick = 0;
/* USER CODE END PV */

void SystemClock_Config(void);
static void MX_GPIO_Init(void);
static void MX_DMA_Init(void);
static void MX_USART2_UART_Init(void);
static void MX_I2C1_Init(void);
static void MX_TIM4_Init(void);
static void MX_USART1_UART_Init(void);
static void MX_SPI1_Init(void);
static void MX_CORDIC_Init(void);
static void MX_TIM6_Init(void);
/* USER CODE BEGIN 0 */
static void on_reply(const STS3215_Reply_t *reply, uint8_t idx, STS3215_Status_t status, void *ctx) {
	if (g_servo_txn == SERVO_TXN_POLL) {
		if (reply->id >= 1 && reply->id <= 12 &&
				(status == STS3215_OK || status == STS3215_ERR_SERVO_FAULT) &&
				reply->data_len >= 8U) {
			uint8_t i = reply->id - 1U;
			g_robot_state.servos[i].position    = (uint16_t)STS3215_UnpackS16LE(&reply->data[0]);
			g_robot_state.servos[i].speed       = STS3215_UnpackSignMag16LE(&reply->data[2], 15U);
			g_robot_state.servos[i].load        = STS3215_UnpackSignMag16LE(&reply->data[4], 10U);
			g_robot_state.servos[i].voltage     = reply->data[6];
			g_robot_state.servos[i].temperature = reply->data[7];
		} else if (reply->id >= 1 && reply->id <= 12 &&
				(status == STS3215_OK || status == STS3215_ERR_SERVO_FAULT) &&
				reply->data_len == 2U) {
			g_robot_state.servo_current[reply->id - 1U] = (int16_t)STS3215_UnpackU16LE(&reply->data[0]);
		}
		return;
	}

	g_reply_id       = reply->id;
	g_reply_error    = reply->error;
	g_reply_status   = status;
	g_reply_data_len = reply->data_len;

	uint8_t copy_len = (reply->data_len <= STS3215_REPLY_DATA_MAX) ? reply->data_len : STS3215_REPLY_DATA_MAX;
	for (uint8_t i = 0; i < copy_len; i++) {
		g_reply_data[i] = reply->data[i];
	}

	g_reply_received = 1;
}

static void on_error(STS3215_HAL_Error_t err, void *ctx)
{
	(void)ctx;
}
__attribute__((used))
int _write(int file, char *ptr, int len)
{
	(void)file;
	for (int i = 0; i < len; i++) {
		if ((ITM->TCR & ITM_TCR_ITMENA_Msk) &&
				(ITM->TER & (1UL << 0U))) {
			ITM_SendChar((uint32_t)(uint8_t)*ptr);
		}
		ptr++;
	}
	return len;
}

void HAL_UART_TxCpltCallback(UART_HandleTypeDef *huart)
{
	if (huart->Instance == USART1) {
		Bridge_TxCpltCallback();
	}
	else if (huart->Instance == USART2) {
		STS3215_HAL_TxCpltCallback(&hservo);
	}
}

void HAL_UARTEx_RxEventCallback(UART_HandleTypeDef *huart, uint16_t Size)
{
	if (huart->Instance == USART1) {
		Bridge_RxEventCallback(Size);
	}
	else if (huart->Instance == USART2) {
		STS3215_HAL_RxEventCallback(&hservo, Size);
	}
}

void HAL_UART_ErrorCallback(UART_HandleTypeDef *huart)
{
	if (huart->Instance == USART1) {
		Bridge_ErrorCallback();
	}
	else if (huart->Instance == USART2) {
		STS3215_HAL_ErrorCallback(&hservo);
	}
}

static void scan_active_servos(void)
{
	uint8_t buf[STS3215_TX_BUF_SIZE];
	active_servo_count = 0;

	for (uint8_t id = 1; id <= 12; id++) {
		int16_t frame_len = STS3215_BuildPing(buf, sizeof(buf), id);
		if (frame_len <= 0) continue;

		g_reply_received = 0;
		hservo.last_error = STS3215_HAL_ERR_NONE;

		if (STS3215_HAL_SendFrame(&hservo, buf, frame_len, false, 1) != STS3215_OK) {
			continue;
		}

		uint32_t t0 = HAL_GetTick();
		while (!g_reply_received && (HAL_GetTick() - t0) < 50U) {
			STS3215_HAL_Process(&hservo);
		}

		if (g_reply_received && hservo.last_error == STS3215_HAL_ERR_NONE) {
			active_servo_ids[active_servo_count++] = id;
		}

		while (!STS3215_HAL_IsIdle(&hservo)) {
			STS3215_HAL_Process(&hservo);
		}
	}

	printf("[SYS] Active servos: %u/%u\r\n", active_servo_count, 12U);
}

static void Imu_Task(void) {
	uint32_t now = HAL_GetTick();
	float dt = (now - g_imu_last_tick) / 1000.0f;
	g_imu_last_tick = now;
	if (dt <= 0.0f || dt > 0.5f) dt = 0.01f;

	BMI088_ReadAccelerometer(&gIMU);
	BMI088_ReadGyroscope(&gIMU);
	Mahony_Update(&g_mahony, gIMU.gyr_rps[0], gIMU.gyr_rps[1], gIMU.gyr_rps[2],
			gIMU.acc_mps2[0], gIMU.acc_mps2[1], gIMU.acc_mps2[2], dt);
}

void Chromapi_SystemInit(void) {
	if (!CordicSqrt_Init(&hcordic)) {
		Error_Handler();
	}
	STS3215_HAL_Init(&hservo, &huart2, 50U, on_reply, on_error, NULL);
	AutoFox_INA226_Constructor(&gINA226);
	AutoFox_INA226_Init(&gINA226, INA226_I2C_ADDR, SHUNT_OHMS, MAX_CURRENT_A);
	Bridge_Init(&huart1);
	(void)BMI088_Init(&gIMU, &hspi1,
			SPI_CS_ACC_GPIO_Port,  SPI_CS_ACC_Pin,
			SPI_CS_GYRO_GPIO_Port, SPI_CS_GYRO_Pin);

	CordicSqrt_Init(&hcordic);
	Mahony_Init(&g_mahony);
	Mahony_Calibrate(&g_mahony, &gIMU);

	Bridge_UpdateCachedPower();

	scan_active_servos();
	HAL_Delay(500U);
	printf("[SYS] System Initialized\r\n");
}
/* USER CODE END 0 */

int main(void)
{

	/* Reset of all peripherals, Initializes the Flash interface and the Systick. */
	HAL_Init();

	/* Configure the system clock */
	SystemClock_Config();

	/* Initialize all configured peripherals */
	MX_GPIO_Init();
	MX_DMA_Init();
	MX_USART2_UART_Init();
	MX_I2C1_Init();
	MX_TIM4_Init();
	MX_USART1_UART_Init();
	MX_SPI1_Init();
	MX_CORDIC_Init();
	MX_TIM6_Init();
	/* USER CODE BEGIN 2 */
	Chromapi_SystemInit();
	HAL_TIM_Base_Start_IT(&htim6);

	/* USER CODE END 2 */

	/* Infinite loop */
	/* USER CODE BEGIN WHILE */
	while (1)
	{

		STS3215_HAL_Process(&hservo);

		if (g_servo_txn != SERVO_TXN_NONE && STS3215_HAL_IsIdle(&hservo)) {
			g_servo_txn = SERVO_TXN_NONE;
		}

		Bridge_Process();
		Bridge_DispatchPendingPositions();

		if (g_imu_task_due) {
			g_imu_task_due = false;
			Imu_Task();
		}

		if (g_power_task_due) {
			g_power_task_due = false;
			Bridge_UpdateCachedPower();
		}

		if (g_poll_due && g_servo_txn == SERVO_TXN_NONE && STS3215_HAL_IsIdle(&hservo)) {
			g_poll_due = false;
			if (active_servo_count > 0) {
				uint8_t buf[STS3215_TX_BUF_SIZE];
				bool current_turn = ((++g_poll_count & 3U) == 0U);
				int16_t frame_len = STS3215_BuildSyncRead(buf, sizeof(buf),
						current_turn ? STS3215_REG_CURRENT_CURRENT : STS3215_REG_CURRENT_POS,
						current_turn ? 2U : 8U,
						active_servo_ids, active_servo_count);
				if (frame_len > 0) {
					g_servo_txn = SERVO_TXN_POLL;
					if (STS3215_HAL_SendFrame(&hservo, buf, (uint16_t)frame_len,
							false, active_servo_count) != STS3215_OK) {
						g_servo_txn = SERVO_TXN_NONE;
					}
				}
			}
		}


		if ((HAL_GetTick() - last_led_update) >= 500U) {
			last_led_update = HAL_GetTick();
			Bridge_UpdateBatteryLed();
		}
		/* USER CODE END WHILE */

		/* USER CODE BEGIN 3 */
	}
	/* USER CODE END 3 */
}

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
/* USER CODE BEGIN 4 */
void HAL_TIM_PeriodElapsedCallback(TIM_HandleTypeDef *htim) {
	if (htim->Instance == TIM6) {
		g_imu_task_due = true;

		if (++g_tim6_div >= 2) {  // 400 Hz / 2 = 200 Hz
			g_tim6_div = 0;
			g_poll_due = true;
		}
		if (++g_tim6_power_div >= 40) {  // 400 Hz / 40
			g_tim6_power_div = 0;
			g_power_task_due = true;
		}
	}
}
/* USER CODE END 4 */
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


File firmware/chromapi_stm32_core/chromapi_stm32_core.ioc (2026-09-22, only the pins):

Mcu.UserName=STM32G431KBTx
PA1.Signal=USART2_DE
PA10.Signal=USART1_RX
PA11.GPIO_Label=IMU_INT_ACC
PA11.Signal=GPXTI11
PA12.GPIO_Label=IMU_INT_GYRO
PA12.Signal=GPXTI12
PA13.Signal=SYS_JTMS-SWDIO
PA14.Signal=SYS_JTCK-SWCLK
PA15.GPIO_Label=I2C_INA_SCL
PA15.Signal=I2C1_SCL
PA2.Signal=USART2_TX
PA3.Signal=USART2_RX
PA4.GPIO_Label=SPI_CS_GYRO
PA4.Signal=GPIO_Output
PA5.GPIO_Label=SPI_IMU_SCK
PA5.Signal=SPI1_SCK
PA6.GPIO_Label=SPI_IMU_MISO
PA6.Signal=SPI1_MISO
PA7.GPIO_Label=SPI_IMU_MOSI
PA7.Signal=SPI1_MOSI
PA9.Signal=USART1_TX
PB0.GPIO_Label=SPI_CS_ACC
PB0.Signal=GPIO_Output
PB3.Signal=SYS_JTDO-SWO
PB4.GPIO_Label=SW_BotLeft
PB4.Signal=GPIO_Input
PB5.GPIO_Label=SW_BotRight
PB5.Signal=GPIO_Input
PB6.GPIO_Label=RGB_LED
PB6.Signal=S_TIM4_CH1
PB7.GPIO_Label=I2C_INA_SDA
PB7.Signal=I2C1_SDA
PF0-OSC_IN.GPIO_Label=SW_TopLeft
PF0-OSC_IN.Signal=GPIO_Input
PF1-OSC_OUT.GPIO_Label=SW_TopRight
PF1-OSC_OUT.Signal=GPIO_Input

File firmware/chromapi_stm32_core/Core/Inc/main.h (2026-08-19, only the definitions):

#define SW_TopLeft_Pin GPIO_PIN_0
#define SW_TopLeft_GPIO_Port GPIOF
#define SW_TopRight_Pin GPIO_PIN_1
#define SW_TopRight_GPIO_Port GPIOF
#define SPI_CS_GYRO_Pin GPIO_PIN_4
#define SPI_CS_GYRO_GPIO_Port GPIOA
#define SPI_IMU_SCK_Pin GPIO_PIN_5
#define SPI_IMU_SCK_GPIO_Port GPIOA
#define SPI_IMU_MISO_Pin GPIO_PIN_6
#define SPI_IMU_MISO_GPIO_Port GPIOA
#define SPI_IMU_MOSI_Pin GPIO_PIN_7
#define SPI_IMU_MOSI_GPIO_Port GPIOA
#define SPI_CS_ACC_Pin GPIO_PIN_0
#define SPI_CS_ACC_GPIO_Port GPIOB
#define IMU_INT_ACC_Pin GPIO_PIN_11
#define IMU_INT_ACC_GPIO_Port GPIOA
#define IMU_INT_GYRO_Pin GPIO_PIN_12
#define IMU_INT_GYRO_GPIO_Port GPIOA
#define I2C_INA_SCL_Pin GPIO_PIN_15
#define I2C_INA_SCL_GPIO_Port GPIOA
#define SW_BotLeft_Pin GPIO_PIN_4
#define SW_BotLeft_GPIO_Port GPIOB
#define SW_BotRight_Pin GPIO_PIN_5
#define SW_BotRight_GPIO_Port GPIOB
#define RGB_LED_Pin GPIO_PIN_6
#define RGB_LED_GPIO_Port GPIOB
#define I2C_INA_SDA_Pin GPIO_PIN_7
#define I2C_INA_SDA_GPIO_Port GPIOB

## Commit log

2026-02-10 adding tps568230 datasheet
    [chromapi_motherboard_v1.kicad_sch]
2026-02-10 First draft of Voltage regulation
    [chromapi_motherboard_v1.kicad_sch]
2026-02-10 Adding hierarchical sheets
    [chromapi_motherboard_v1.kicad_sch, peripherals.kicad_sch, pwr_supply_charge.kicad_sch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]
2026-02-11 First draft of audio amplifier
    [chromapi_motherboard_v1.kicad_sch, peripherals.kicad_sch, pwr_supply_charge.kicad_sch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]
2026-02-11 Updating audio amplifier
    [peripherals.kicad_sch]
2026-02-12 Adding IMU
    [chromapi_motherboard_v1.kicad_sch, peripherals.kicad_sch, pwr_supply_charge.kicad_sch]
2026-02-12 Finishing IMU schematic
    [peripherals.kicad_sch]
2026-02-12 Adding Force Resistive Sensor
    [chromapi_motherboard_v1.kicad_sch, peripherals.kicad_sch]
2026-02-12 Updating microphone schematic
    [peripherals.kicad_sch, pwr_supply_charge.kicad_sch]
2026-02-13 Updating peripherals
    [peripherals.kicad_sch, pwr_supply_charge.kicad_sch, rpi_interface.kicad_sch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]
2026-02-13 Component sizing in voltage regulator
    [tps568230.kicad_sch]
2026-02-13 Updating voltage regulation schematic
    [tps568230.kicad_sch]
2026-02-16 Adding 5V to 3V3 regulator
    [stm32_mcu_core.kicad_sch, tps568230.kicad_sch]
2026-02-18 Adding BMS
    [peripherals.kicad_sch, pwr_supply_charge.kicad_sch, stm32_mcu_core.kicad_sch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]
2026-02-18 Adding datasheets
    [pwr_supply_charge.kicad_sch]
2026-02-18 First draft of rpi interface
    [rpi_interface.kicad_sch]
2026-02-19 Finishing power supply and charge schematic
    [pwr_supply_charge.kicad_sch]
2026-02-19 minor fix
    [pwr_supply_charge.kicad_sch]
2026-02-19 Adding voltage divider to EN
    [tps568230.kicad_sch]
2026-02-19 Adding logo
    [chromapi_motherboard_v1.kicad_sch, peripherals.kicad_sch, pwr_supply_charge.kicad_sch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]
2026-02-19 Adding LED datasheet
    [peripherals.kicad_sch, rpi_interface.kicad_sch]
2026-02-19 Adding rpi interface
    [rpi_interface.kicad_sch]
2026-02-20 Adding pin assignements to stm32_mcu_core
    [stm32_mcu_core.kicad_sch]
2026-02-21 Schematic first draft
    [chromapi_motherboard_v1.kicad_sch, peripherals.kicad_sch, rpi_interface.kicad_sch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]
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2026-02-21 minor fixes
    [chromapi_motherboard_v1.kicad_sch, peripherals.kicad_sch, pwr_supply_charge.kicad_sch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]
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2026-02-21 Adding descriptions & datasheets
    [peripherals.kicad_sch, pwr_supply_charge.kicad_sch, stm32_mcu_core.kicad_sch]
2026-02-21 Adding power LED status
    [peripherals.kicad_sch, pwr_supply_charge.kicad_sch, rpi_interface.kicad_sch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]
2026-02-22 Adding footprint & symbol folders
    [chromapi_motherboard_v1.kicad_sch, peripherals.kicad_sch, pwr_supply_charge.kicad_sch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]
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2026-02-28 Replacing AO4406A by PSMN1R5-30YLC
    [chromapi_motherboard_v1.kicad_pcb, pwr_supply_charge.kicad_sch]
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2026-03-06 adding chromapi logo to library
    [chromapi_motherboard_v1.kicad_pcb, chromapi_motherboard_v1.kicad_sch]
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2026-03-08 adding inductor 3d model
    [chromapi_motherboard_v1.kicad_pcb, pwr_supply_charge.kicad_sch, tps568230.kicad_sch]
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2026-03-11 Applying first corrections from first review
    [chromapi_motherboard_v1.kicad_sch, peripherals.kicad_sch, stm32_mcu_core.kicad_sch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]
2026-03-12 Schematic servo tranceiver correction
    [chromapi_motherboard_v1.kicad_pcb, chromapi_motherboard_v1.kicad_sch, peripherals.kicad_sch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]
2026-03-15 IMU modification and Power monitor addition
    [chromapi_motherboard_v1.kicad_pcb, chromapi_motherboard_v1.kicad_sch, peripherals.kicad_sch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]
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2026-03-16 Replacing MOSFET for CSD17581Q3A
    [chromapi_motherboard_v1.kicad_pcb, chromapi_motherboard_v1.kicad_sch, peripherals.kicad_sch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]
2026-03-16 Drawing rpi outline & placement update
    [chromapi_motherboard_v1.kicad_pcb]
2026-03-17 Upgrading voltage regulation circuit in schematic
    [peripherals.kicad_sch, rpi_interface.kicad_sch, servo_control.kicad_sch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]
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2026-04-08 Finishing first draft of routing
    [chromapi_motherboard_v1.kicad_pcb]
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2026-04-08 Adding schematic & bom
    [chromapi_motherboard_v1.kicad_pcb]
2026-04-10 Adding external pullup to NRST
    [chromapi_motherboard_v1.kicad_pcb, peripherals.kicad_sch, pwr_supply_charge.kicad_sch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]
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2026-04-10 Updating MPN and part number
    [chromapi_motherboard_v1.kicad_pcb, chromapi_motherboard_v1.kicad_sch, peripherals.kicad_sch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]
2026-04-11 Adding image to schematic
    [chromapi_motherboard_v1.kicad_pcb, chromapi_motherboard_v1.kicad_sch]
2026-04-12 Fixing DRC
    [chromapi_motherboard_v1.kicad_pcb]
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2026-04-13 Adding MPN to parts
    [chromapi_motherboard_v1.kicad_pcb, chromapi_motherboard_v1.kicad_sch, peripherals.kicad_sch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]
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2026-04-29 Adding IMU reference frame for silkscreen
    [chromapi_motherboard_v1-B_Cu-SIGNAL.gbr, chromapi_motherboard_v1-B_Mask.gbr, chromapi_motherboard_v1-B_Paste.gbr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]
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2026-05-11 fixing DMA for sk6812
    [chromapi_stm32_core.ioc, main.c]
2026-05-25 note on audio issue
    [chromapi_motherboard_v1.kicad_pcb, chromapi_motherboard_v1.kicad_sch, servo_control.kicad_sch]
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2026-06-02 Add todo for speaker connector
    [chromapi_motherboard_v1.kicad_sch]
2026-06-10 swap contact switches logic
    [bridge.c]
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2026-06-22 update ioc according to fix spi conf
    [chromapi_stm32_core.ioc, main.c, main.h]
2026-06-23 fix spi connection mismatch
    [chromapi_motherboard_v1.kicad_pcb, chromapi_motherboard_v1.kicad_sch]
2026-06-23 [fixed] change the connector footprint for the speaker
    [chromapi_motherboard_v1.kicad_pcb, chromapi_motherboard_v1.kicad_sch]
2026-06-23 [fix] change the connector footprint for the speaker
    [chromapi_motherboard_v1.kicad_sch, peripherals.kicad_sch]
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2026-07-02 remove rgb led capactiors
    [stm32_mcu_core.kicad_sch]
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2026-07-08 update clearance
    [chromapi_motherboard_v1.kicad_pcb]
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2026-07-09 adding vias under buck
    [chromapi_motherboard_v1.kicad_pcb]
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2026-07-10 fix bom
    [chromapi_motherboard_v1.kicad_pcb, peripherals.kicad_sch, voltage_regulation.kicad_sch]
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2026-07-10 bom optimisation for pcba
    [chromapi_motherboard_v1.kicad_pcb, peripherals.kicad_sch, pwr_supply_charge.kicad_sch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]
2026-07-10 update image and schematic plot
    [chromapi_motherboard_v1.kicad_pcb, chromapi_motherboard_v1.kicad_sch]
2026-07-10 update gerbers & step files
    [chromapi_motherboard.step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]
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2026-08-02 update led commands & pcb 3D model
    [chromapi_motherboard.step, chromapi_motherboard_v1.kicad_pcb, rpi_interface.kicad_sch]
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2026-08-12 fix R27/R27 resistor references
    [chromapi_motherboard_v1-B_Cu-SIGNAL.gbr, chromapi_motherboard_v1-B_Mask.gbr, chromapi_motherboard_v1-B_Paste.gbr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]
2026-08-23 pcb minor fixes
    [chromapi_motherboard_v1-B_Cu-SIGNAL.gbr, chromapi_motherboard_v1-B_Mask.gbr, chromapi_motherboard_v1-B_Paste.gbr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]
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2026-10-14 fix mahony frame orientation according to onshape
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2026-11-10 fix charge LED colors, silkscreen & regenerate outputs
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

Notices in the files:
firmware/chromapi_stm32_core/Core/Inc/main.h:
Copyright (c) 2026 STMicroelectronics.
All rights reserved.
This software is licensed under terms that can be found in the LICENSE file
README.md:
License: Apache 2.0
